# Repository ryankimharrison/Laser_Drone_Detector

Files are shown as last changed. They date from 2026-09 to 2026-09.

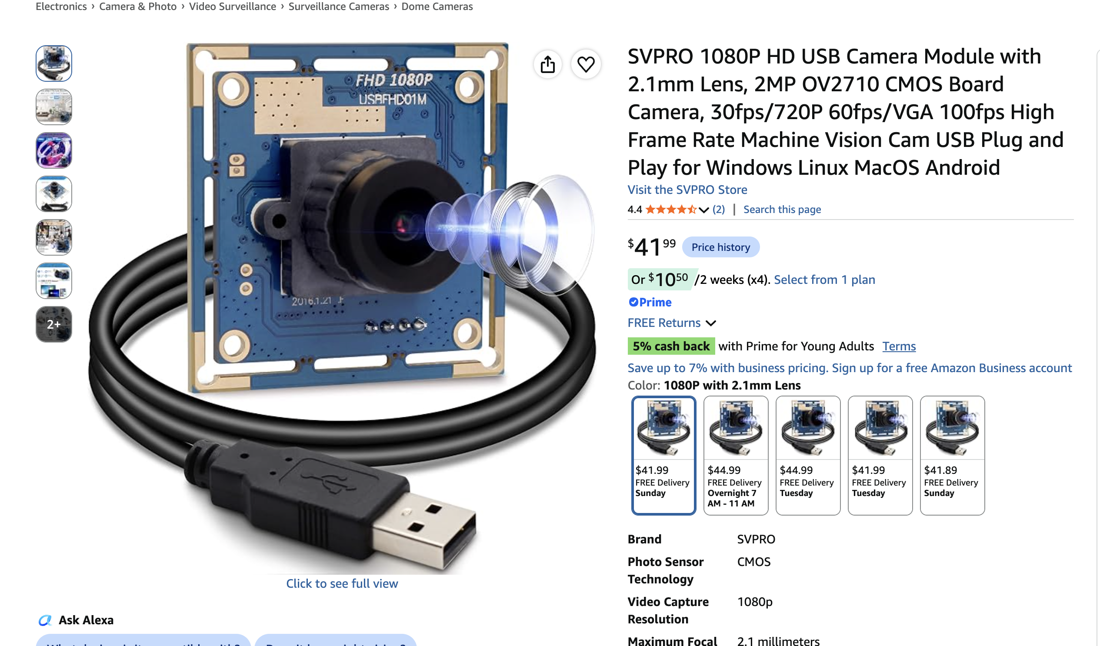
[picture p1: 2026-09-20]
unnamed (1).png

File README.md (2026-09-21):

# Laser Turret

An experimental two-camera pan/tilt tracking platform that detects a handheld DGI drone, follows it with a differential stepper mechanism, and controls a low-power green laser through a deliberately fail-closed software interlock.

This README explains both the big picture and the implementation. In plain language: a Windows computer watches two cameras, identifies the drone, estimates where it is moving, and asks a Raspberry Pi Pico to turn two motors. The laser is a separate output. Tracking the drone does **not** automatically permit the laser to turn on; a set of additional checks must all pass on every control cycle.

## What is in this repository?

| Area | Purpose |
|---|---|
| `turret_host/` | Windows/Python application: cameras, object and face detection, tracking, motion control, GUI, calibration, logging, and serial communication |
| `firmware/current/` | Current MicroPython firmware for the Raspberry Pi Pico |
| `turret-2026-03-27_134819/` | KiCad schematic and PCB layout for controller board revision `3/27/2026 prod v1` |
| `tools/` | Calibration, deployment, diagnostics, replay, registration, and analysis utilities |
| `tests/` | Host-side regression tests, principally for telemetry and microstepping |
| `dataset/`, `models/`, `weights/` | Local training data and detector artifacts; most generated content is intentionally ignored by Git |
| `firmware/backups/` | Historical, timestamped firmware snapshots; useful for archaeology, not the current implementation |
| `staged/` | Proposed patches and experiments that may not be active |

The authoritative implementation paths are `turret_host/`, `firmware/current/`, and the KiCad project. Documents such as `AGENT_HANDOFF.md`, `DETECTION_BRIEF.md`, session notes, and staged patches preserve valuable history, but some statements in them have since been superseded by measurements or code changes.

## System overview

The physical head carries a narrow camera, a wide camera, a laser, and an inertial measurement unit (IMU). Two stepper motors drive a differential wrist. The computer performs the expensive vision and tracking work; the Pico generates accurate step pulses, applies motion limits, operates switched outputs, and stops motion if host commands disappear.

```mermaid
flowchart LR
    W[Wide camera<br/>find and reacquire] --> DW[Wide detector]
    N[Narrow camera<br/>precision tracking] --> DN[Drone detector]
    N --> F[YuNet face detector]
    DW --> X[Wide-to-narrow mapping]
    DN --> T[Pixel tracker]
    X --> T
    T --> C[Controller]
    F --> I[Laser interlock]
    C --> I
    I --> L[Serial link]
    L --> P[Raspberry Pi Pico]
    P --> M[Two stepper drivers]
    P --> Q[Laser MOSFET]
    IMU[Payload IMU] --> P
    P --> L
```

The design separates responsibilities:

- The **host computer** understands images, chooses a target, predicts motion, calculates motor rates, presents status, and decides whether the laser is permitted.
- The **Pico firmware** performs deterministic pulse generation, differential kinematics, acceleration limiting, travel guarding, output control, and a 400 ms command watchdog.
- The **PCB** connects power, the Pico, plug-in stepper drivers, motor and sensor headers, and three MOSFET-switched loads.

## How one frame becomes motion

1. Dedicated capture threads continuously grab the newest narrow and wide camera frames.
2. YOLO detects candidate drones. Wide-camera detections can help find a target outside the narrow field of view.
3. A stateful pixel tracker associates detections across frames and estimates position and velocity.
4. The controller compares the predicted target position with the calibrated laser aim point.
5. A measured image Jacobian converts the required image motion into signed rates for the two motors.
6. The host sends `vel <motor-a> <motor-b>` commands over USB serial.
7. The Pico ramps toward those rates and generates step pulses using RP2040 PIO hardware.
8. If new commands stop arriving for 400 ms, the firmware ramps the motors to zero and cuts the laser.

Instead of queues, threads exchange data through a `Slot`: a one-item, newest-wins mailbox. This is important for real-time behavior. If vision falls behind, processing an old queue of frames would make the turret chase where the target *was*. A slot lets a slow consumer skip frames and act on the freshest available observation.

## Computer vision and target tracking

### Two cameras, two roles

The **wide camera** provides situational awareness and reacquisition. It is an SVPRO USBFHD01M/OV2710 module with an approximately 108° horizontal field of view. It normally runs at 1920×1080 at 30 fps, with an optional 1280×720 at 60 fps mode.

The **narrow camera** is a Logitech C270 running at 1280×720 at 30 fps. It provides the precision image coordinate system used by the tracker, controller, laser calibration, and safety checks. It is physically mounted 90° clockwise and has had its IR-cut filter removed. That improves some sensing possibilities but shifts its colors away from what ordinary pretrained vision models expect.

The wide-to-narrow transformation can steer the turret toward a target seen only by the wide camera. It includes camera rotation, focal-length scaling, and optional fitted registration. However, parallax and calibration error mean a wide-origin box is never considered precise enough to authorize the laser. The design rule is:

> **Track on either camera; fire only from current narrow-camera evidence.**

### Drone detection

`turret_host/detector.py` wraps an Ultralytics YOLO detector. The active default is the project-specific `drone_y11n_v4_1280.pt`, run at 1280-pixel input size with FP16 enabled where supported. Only the `drone` class is selected.

The detector proposes boxes; it does not by itself decide which box to follow or whether the laser may operate. Training and capture utilities support collecting in-domain images, pre-labeling them, reviewing labels, and training a small model. This matters because the real scene—a close drone held in a hand, indoors, with partial occlusion and altered camera color response—is unlike the small outdoor drones found in most public datasets.

### Association and prediction

`turret_host/tracker.py` implements a pixel-space Kalman tracker with state:

```text
[horizontal position, vertical position, horizontal velocity, vertical velocity]
```

It uses confidence, spatial gating, box geometry, and continuity to associate detections. Adaptive process noise lets it remain smooth during steady motion while responding more quickly when the target changes direction. Its state machine is:

- `SEARCH`: no reliable target.
- `ACQUIRE`: a candidate is being confirmed.
- `TRACK`: the detector and filter agree on a target.
- `COAST`: detections were briefly lost, so the filter is predicting without fresh pixel evidence.

Coasting is useful for smooth pointing but is **not** sufficient permission to fire. The interlock requires a fresh narrow-camera drone box, not just a plausible prediction.

Range is estimated from apparent drone size when possible and may be supplemented by camera geometry. The assumed physical drone width is part of the configuration, so this is an estimate rather than a depth sensor measurement.

### Motion compensation and control

The controller combines two ideas:

- **Proportional correction** moves the target toward the goal pixel.
- **Feedforward** uses estimated target velocity so the turret moves with the target instead of always lagging behind it.

The core control law is conceptually:

```text
motor rate = - inverse(image Jacobian) × (position correction + target image velocity)
```

The image Jacobian is measured during calibration by moving the mechanism and observing how a stationary scene shifts in the camera. Its sign and scale are machine-specific. Rates are clamped, derated near travel limits, and converted through the differential mechanism. Optical flow and IMU-derived platform motion can improve the velocity estimate; their quality gates and fallbacks are logged so recorded runs can be analyzed rather than tuned by impression.

## How face protection works

The active face detector is OpenCV YuNet. It runs in a dedicated thread on the **narrow camera** because CPU inference can take longer than one camera frame period. YuNet expects upright faces, so the narrow image is rotated to compensate for the camera's 90° physical mounting. Detected boxes are then mapped back to the raw narrow-camera coordinate system used by tracking and control.

The interlock measures the distance between every detected face box and the intended beam path. The path is treated as a segment between the calibrated laser goal and current target location rather than as a single point. If a face is within the configured 120-pixel exclusion margin, the laser is inhibited.

Just as importantly, a missing or old face report is treated as **unknown**, not “no face.” A stalled detector, dead camera thread, clock error, or face result older than 200 ms therefore turns the laser off.

### The laser permission checklist

`LaserInterlock` grants permission only when **all** of the following are true:

| Check | Meaning |
|---|---|
| Armed | Both configuration and the operator's deliberate arm action allow laser use |
| Tracking | The tracker is in confirmed `TRACK`, not searching, acquiring, or coasting |
| Goal calibrated | The image location where the beam lands has been physically measured |
| Fresh drone lock | A recent narrow-camera drone box exists and contains the entire beam path |
| Plausible shape | The box aspect ratio is consistent with the measured drone, rejecting a known hand-like false positive |
| Fresh face report | The face detector has reported recently enough to be trusted |
| Face clear | Every face is farther than the inhibit margin from the beam path |
| Settled | The platform angular rate is below the firing threshold |
| Aim error small | The tracked target is close enough to the calibrated beam point |
| Velocity stream fresh | A motion command was successfully sent within the last 100 ms |
| Duty limit | Continuous on-time has not exceeded the configured cap; a cooldown follows a trip |

The logic is permission-based: a current drone detection under the beam is positive evidence. Merely failing to see a face is never enough. On any failed check, the desired laser state changes to off before normal motion work continues.

Additional protections include:

- Operator stop, disarm, E-stop, shutdown, and dead-worker events set a host-side **latched safety veto**. It can only be cleared by a new human arm action.
- Arming on real hardware invokes a live face-interlock verification procedure.
- A refused firmware `laser on` is not retried forever.
- The serial writer prioritizes laser state transitions and reports when a dead link makes software unable to confirm that the beam is off.
- Firmware boot and exception paths park STEP/DIR and all MOSFET gates low.
- The velocity watchdog cuts the laser as well as stopping motion.

### What this protection cannot guarantee

The software currently detects **visible faces**, not all human heads. YuNet can miss profiles, the back of a head, heavy occlusion, poor lighting, motion blur, or a strongly tilted face. The repository records a known loss around 35° of in-plane head tilt in one test configuration. The 200 ms allowable report age also permits real-world motion within the safety margin.

Only narrow-camera faces participate in the firing veto. Wide-camera face boxes are drawn for awareness but are not geometrically calibrated into the beam coordinate system and do not gate the laser.

No software command can switch off a laser after power or serial control has failed in a state that leaves the output energized. A physical, normally-off power interlock, keyed enable, emergency stop that removes laser power, enclosure/beam stop, and appropriate protective eyewear are outside this repository and remain necessary. Cheap 532 nm DPSS modules may also emit invisible infrared unless properly filtered.

## Firmware architecture

The firmware runs on a Raspberry Pi Pico/RP2040 under MicroPython.

| Module | Responsibility |
|---|---|
| `main.py` | Safe boot, pin parking, and console startup |
| `cli.py` | USB serial command protocol and operational workflows |
| `stepper.py` | PIO step generation, position moves, velocity loop, acceleration, watchdog, and optional microstep profiles |
| `kinematics.py` | Differential transform between motor motion and payload pitch/yaw |
| `guard.py` | IMU-backed crash/travel protection |
| `imu.py` | GY-85 gyro, accelerometer, and magnetometer drivers |
| `datum.py` | Gravity/yaw datum handling |
| `endstop.py` | Endstop debouncing, homing, and repeatability tests |
| `peripherals.py` | Laser, IR light, fan, ultrasonic, analog, and I²C devices with safety checks |
| `pinmap.py` | Copper-verified board wiring; the hardware source of truth |
| `config.py` | Driver type, mechanics, limits, interlocks, and timing |
| `diagnostics.py` | Electrical and motion self-tests |

The differential wrist is not a conventional independent pan motor plus tilt motor. Both motors moving in the same direction produce pitch; moving oppositely produces yaw. Each motor by itself produces a mixture. `kinematics.py` performs this transform using the 26-tooth motor and 60-tooth miter pulley ratio.

Position moves and continuous velocity mode use RP2040 PIO state machines for deterministic pulses. A 5 ms firmware velocity tick ramps rates and enforces limits. Dynamic microstepping exists but is disabled by default because measured switching disturbances outweighed its benefit on this drivetrain.

## PCB and hardware design

The KiCad design is a single controller/carrier board centered on:

- **A1 — Raspberry Pi Pico:** USB-connected control computer and I/O controller.
- **A2/A3 — Pololu-format stepper sockets:** intended symbol is DRV8825, while the installed/configured drivers are A4988-compatible modules.
- **U1 — XL1509-5.0 buck regulator:** creates the board's 5 V rail from the external motor supply, with L1, D1, and bulk capacitors.
- **Q1/Q2/Q4 — low-side N-channel MOSFET outputs:** switch the laser, IR illuminator, and fan.
- **J2/J3:** four-wire motor coil connectors.
- **J13/J14:** endstop connectors.
- **J5/J11:** sensor/I²C connections; the GY-85 is configured on J5/I²C0.
- **J10/J9/J7:** laser, IR, and fan switched-load connectors.

The Pico is USB-powered; the PCB's 5 V rail does not feed Pico `VSYS`. Grounds are common. This means the controller does not operate as a standalone board without USB power.

### GPIO summary

| Function | GPIO |
|---|---:|
| Tilt motor DIR / STEP | 0 / 1 |
| Tilt microstep M2/M1/M0 / enable | 2 / 3 / 4 / 5 |
| Tilt driver pad 2 | 6 |
| Pan motor DIR / STEP | 7 / 8 |
| Pan microstep M2/M1/M0 / enable | 9 / 10 / 11 / 12 |
| Pan driver pad 2 | 13 |
| IR / fan / endstop 1 / laser | 14 / 15 / 16 / 17 |
| Endstop 2 | 19 |
| J5 I²C0 SDA/SCL | 20 / 21 |
| J11 I²C1 SDA/SCL | 26 / 27 |
| Analog input | 28 / ADC2 |

### Important PCB findings and rework

These are facts encoded in `firmware/current/pinmap.py` and `config.py`, not generic warnings:

1. **Tilt STEP and DIR net labels are swapped in the schematic.** The copper is usable; firmware follows the physically verified GPIO0=DIR and GPIO1=STEP mapping.
2. **Driver socket pad 2 differs between DRV8825 and A4988.** It is `FAULT` on a DRV8825 but logic `VDD` on an A4988. The current configuration drives it from a Pico GPIO as an acknowledged, marginal workaround; the documented preferred rework is a proper 3.3 V connection.
3. **RESET/SLEEP is reportedly tied to 5 V.** This violates the A4988 input limit when its logic supply is 3.3 V and is explicitly recorded as an accepted out-of-spec condition, not a safe design recommendation.
4. **Several sensor connectors expose 5 V next to direct RP2040 inputs.** The ultrasonic echo, analog sensor return, and powered endstop arrangements have no divider or clamp. RP2040 GPIO is not 5 V tolerant; only dry-contact-to-ground endstops or verified 3.3 V signals are safe.
5. **The motor connectors are mirrored.** Each keeps a coil on adjacent pins, but supplied interleaved looms must be re-pinned so each coil occupies pins 1–2 or 3–4. Incorrect wiring can make a motor buzz and overheat its driver.
6. **The TO-220 MOSFET footprint pin order did not match a standard device.** Q1/Q2/Q4 require crossed gate/drain leads or a matching pinout. Current config says this rework was completed; verify the physical board.
7. **There are no on-board I²C pull-ups.** Any attached module must provide correctly referenced 3.3 V pull-ups.

For any new revision, these should be corrected in copper instead of perpetuated as assembly workarounds.

## Homing, calibration, and coordinate systems

The turret has multiple coordinate systems: wide pixels, raw narrow pixels, upright display pixels, motor microsteps, payload pitch/yaw, and the real laser spot. Calibration is what connects them.

At startup, the normal application establishes a repeatable datum by checking the link, calibrating gyro bias, leveling from gravity, finding a yaw reference, applying a consistent backlash preload, and setting home. Pitch is observable from gravity. Yaw is not; the project uses the repeatable magnetic field of the nearby motors as a local datum rather than trusting it as a compass.

Required calibration artifacts include:

- **Image Jacobian:** how motor steps move a stationary feature in the narrow image.
- **Goal pixel:** where the real laser spot lands in the narrow image. Frame center is acceptable for aiming experiments but never for firing permission.
- **Wide-to-narrow registration:** how a wide detection maps into the narrow camera for reacquisition.
- **Camera/latency measurements:** focal geometry, exposure, frame delivery, and end-to-end delay.

Mechanical backlash was measured around 0.57°, so homing approaches the final datum from a consistent direction.

## Running the software

The recorded development environment is Windows with Python 3.12, OpenCV, NumPy, Pillow, pyserial, PyTorch with CUDA, and Ultralytics. A `.venv` directory exists in this checkout, but virtual environments are machine-specific and its Python launcher may point to an interpreter that is no longer installed. The repository currently has no reproducible lock file; treat the environment description as informative rather than a clean-install guarantee, and rebuild the environment locally when necessary.

Start safely with simulation and no GUI:

```powershell
.\.venv\Scripts\python.exe -m turret_host.app --no-hardware --no-gui --run-seconds 5
```

Run simulation with the spectator GUI:

```powershell
.\.venv\Scripts\python.exe -m turret_host.app --no-hardware
```

Run with real cameras and motion but force tracking-only behavior:

```powershell
.\.venv\Scripts\python.exe -m turret_host.app --tracking-only
```

The real-hardware default performs homing and may move the mechanism. Keep the laser power physically disconnected during commissioning. Useful options include `--port`, `--cpu`, `--wide-fast`, `--fast-home`, `--skip-level`, `--record DIR`, and `--run-seconds N`; use `--help` for the current list.

## Verification and diagnostics

Tests that do not require attached hardware:

```powershell
.\.venv\Scripts\python.exe -m compileall -q turret_host
.\.venv\Scripts\python.exe -m unittest discover -s tests
.\.venv\Scripts\python.exe -m turret_host.control
.\.venv\Scripts\python.exe -m turret_host.tracker
```

Many utilities in `tools/` intentionally talk to real hardware or cameras. Read their arguments and source before running them. In particular, deployment, homing, calibration, step, lash, and structured-light tools can cause motion or light emission.

The application can record synchronized telemetry for after-action analysis. The supporting scripts study latency, clock alignment, step integrity, image registration, optical-flow velocity, aim residuals, and mechanical skew. This measurement-first approach is central to the project: motor counts alone cannot reveal a skipped belt or stalled mechanism, and a visually smooth demo does not prove that the safety gates worked.

## Known limitations and current status

- This working tree is an active prototype with uncommitted current-code changes and staged experiments.
- Laser enable is currently `True` in both `turret_host/config.py` and `firmware/current/config.py`. The GUI still requires deliberate arming and the interlock still applies, but configuration is not a physical safety barrier.
- Face detection is a safety aid with known blind spots, not proof that no head is present.
- Wide-camera detections can steer but cannot authorize firing.
- Several camera intrinsics and offsets began as estimates; verify which calibration JSON artifacts exist on the actual machine.
- Dead reckoning can diverge when motors skip. The payload accelerometer independently measures tilt, but it cannot directly observe yaw near level.
- The software soft limits do not replace mechanical stops. The payload is documented as ±90° pitch with a ±225° yaw wiring limit.
- The host presently caps normal motor commands at 1000 microsteps/s pending further delivery testing, below firmware's higher electrical ceiling.
- Hardware notes describe accepted out-of-spec wiring. A production revision should add real level shifting/protection and a hardware laser-interlock chain.

## Design principles worth preserving

- **Fail closed:** uncertainty removes permission; it never creates it.
- **Freshness is data:** every frame, face report, detection, and command carries time information.
- **Newest wins:** discard stale work instead of building a real-time backlog.
- **Measure geometry:** do not hide sign errors or physical offsets in tuning constants.
- **Separate tracking from firing:** a prediction may steer, but only current narrow-camera evidence can permit light.
- **Independent witnesses:** use camera evidence, serial freshness, IMU attitude, firmware watchdogs, and human controls for different failure modes.
- **Preserve provenance:** a mapped wide-camera box remembers that it came from the wide camera and can never accidentally become firing evidence.

## Further reading

- `turret_host/BUILD_SPEC.md` — host design contract and hard-won implementation constraints.
- `turret_host/STATUS.md` — an older formal safety review; useful history, but some configuration values are now outdated.
- `AGENT_HANDOFF.md` — detailed hardware measurements, firmware protocol, and project history.
- `DETECTION_BRIEF.md` — rationale for the custom drone dataset and detector training approach.
- `PLAN_NEXT_STAGE.md` and session notes — experimental results and next-stage control analysis.
- `firmware/current/pinmap.py` — the copper-verified wiring source of truth.

## Responsible use

This project combines automated aiming, moving machinery, exposed electronics, and laser emission. Operate it only in a controlled indoor test area with a beam stop, exclusion zone, direct supervision, and a physical means to remove laser power. Begin with the laser disconnected and substitute a harmless indicator during software development. Compliance with local laser, electrical, workplace, and aviation rules is the operator's responsibility.

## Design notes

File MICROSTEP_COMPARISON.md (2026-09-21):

# Dynamic microstepping and fixed-mode comparison

## Faster tracking: dynamic mode

`--dynamic-microstep` now enables automatic 1/16 <-> 1/8 switching and doubles
the narrow tracking angular-speed ceiling. This is different from the fixed
A/B comparison below, which deliberately preserves angular speed.

The implementation is local and offline-tested; it has NOT been deployed or
validated on the mechanism. Deploy the updated firmware first (see below).

```powershell
./.venv/Scripts/python.exe -m turret_host.app --dynamic-microstep --tracking-only --skip-level --record diag/microstep_dynamic
```

Return to baseline with a separate launch after closing the first one:

```powershell
./.venv/Scripts/python.exe -m turret_host.app --microstep 16 --tracking-only --skip-level --record diag/microstep_baseline
```

No new camera/Jacobian/goal-pixel calibration is required solely for this
mode. The host retains fixed 1/16 units and the existing Jacobian. The new
`vel16` firmware command converts EVERY request to the current physical gear,
including commands after a shift. Calibration files are not rewritten.

With the current 1,000 pulse/s baseline:

| Behavior | Fine 1/16 | Coarse 1/8 |
|---|---:|---:|
| Physical pulse cap per motor | 1,000/s | 1,000/s |
| Nominal pure-axis angular cap | 48.75 deg/s | 97.5 deg/s |
| Angular acceleration | unchanged | unchanged |

These are commanded ceilings, not a claim that the loaded motors achieve
them. Wide-only acquisition keeps the old angular cap because its evidence
arrives more slowly. This version does not use 1/4 steps.

Shifting policy is based on the faster motor's demand in 1/16-equivalent
units: request coarse above 700/s for 100 ms; request fine below 400/s for
300 ms, and only once the ramped commanded rate is also below 400/s. There
must be at least 500 ms between shifts. Coarsening is deferred when the
existing phase estimate is unaligned; it is never forced after a timeout.
While deferred, the fine pulse cap remains in effect.

Both driver modes change with the timer ISR excluded and both PIO generators
paused. Travel limits use fixed units, counters retain fractional progress,
and `velmode off` restores 1/16 before homing/rewinding. The existing phase
estimate is dead reckoning, NOT a hardware pulse counter: software tests do
not establish physical translator alignment or absence of shift-induced
motion. First hardware runs must check for jolts, oscillation and lost steps.

For the first comparison, record baseline -> dynamic -> baseline with the
same target motions and range, starting slowly and increasing movement speed.
Use `--tracking-only` during these tests. Judge target retention and error
together with IMU motion and the shutdown return check. A higher requested
speed without delivered motion is not an improvement.

`control.jsonl` now includes `gear_ack`: the last acknowledged physical
divisor, cumulative shifts, firmware pulse-cap flag, canonical requested
rates and `ack_t`. The timestamp matters: it is a previous serial ACK, not
necessarily the command on the same control row. `session.json` records
`DYNAMIC_MICROSTEPPING`, `MICROSTEP_DIVISOR` and the actual host caps.

The host refuses dynamic firmware without protocol version 2. The firmware
refuses legacy `vel` commands while dynamic mode is enabled; use the host's
new protocol, or select `microprofile 16` while idle to leave dynamic mode.

## Fixed-speed comparison

Implemented locally; hardware validation is pending. Use `--microstep 16` or
`--microstep 8` on each application launch. Close the application completely
between runs so only one process owns the serial port.

## Firmware prerequisite

The board must have the updated `cli.py` and new `microprofile.py`. An older
board is rejected before homing; the application never silently falls back to
`ms both 8`. The normal deployment tool is:

```powershell
./.venv/Scripts/python.exe tools/deploy.py --dry-run
./.venv/Scripts/python.exe tools/deploy.py --label fixed-microstep-profiles
```

The deploy tool uploads all changed files in `firmware/current`, including any
pre-existing changes there, and resets the board. Review the dry-run list first.
No firmware was deployed as part of implementing this feature.

## A/B runs

If the old watchdog latch prevents startup, with the app CLOSED:

```powershell
./.venv/Scripts/python.exe tools/send.py "laser off" "velmode on" "velmode off" "state"
```

This clears the velocity latch; it does not test motor delivery. Confirm the
returned state has velocity stopped, both axes idle, and laser off. The
microprofile command refuses a moving or illuminated rig.

Run A:

```powershell
./.venv/Scripts/python.exe -m turret_host.app --microstep 16 --tracking-only --skip-level --record diag/microstep16
```

Run B, after A has fully closed:

```powershell
./.venv/Scripts/python.exe -m turret_host.app --microstep 8 --tracking-only --skip-level --record diag/microstep8
```

`--skip-level` retains the project's existing startup choice. It still runs
the rest of homing; it is not a way to skip setup or verify the starting pose.
Place the mechanism at the same sensible starting pose for both runs.
`--tracking-only` refuses ARM for the entire process. Press START in the GUI.
The recorder creates a timestamped run subdirectory under each requested path.

Use the same lighting, distance and target in each run:

1. Hold the drone stationary for 10 seconds.
2. Make repeatable horizontal passes, then vertical passes, then reversals.
3. Repeat increasingly fast passes, including briefly leaving the narrow view.
4. Close normally and retain the shutdown/step-integrity report.

Two runs give an initial comparison. A third 1/16 run (A/B/A), or a reversed
order repeat, helps distinguish microstepping from warming motors/drivers and
differences in hand movement. Compare visible target retention and reacquisition,
pixel error, saturation, and measured IMU motion versus commanded motion.
Exclude homing, actual travel-limit stops, and false target locks from motor
delivery comparisons. Convert pulse rates using each run's
`session.json` config `AXIS_STEP_DEG`; raw pulse rates are not comparable.

## What is preserved

The initial experiment holds angular limits constant: with the current 1,000
pulse/s baseline, 1/8 uses 500 pulse/s, yielding the same nominal 48.75 deg/s
pure-axis cap. Firmware position rates and accelerations are scaled too;
velocity acceleration is scaled exactly once. This tests whether the motor
follows more reliably/smoothly, not whether requesting twice the speed helps.
A speed-ceiling sweep is a separate hardware experiment after this passes.

The host doubles the loaded Jacobian at 1/8, halves step-based caps/preload,
and updates the angular conversion. Existing untagged Jacobian files are
interpreted as 1/16. New calibration saves record `microstep_divisor`, allowing
either mode to load them correctly. Launching alone never writes calibration.
The GUI's Jacobian calibration uses scaled probe travel. Camera intrinsics,
registration and goal-pixel files are not changed.

Switching occurs only before homing, never during tracking. Before coarsening,
the firmware may move each motor by ONE 1/16 microstep to reach a common driver
translator phase. Homing then establishes the datum. Automatic gearshifting
stays off. The selected mode remains on the board until changed or rebooted;
use `--microstep 16` to return to baseline. Launching without a profile while
the board remains at 1/8 is rejected by the existing homing geometry check.

## Offline verification

```powershell
./.venv/Scripts/python.exe -m unittest discover -s tests -p '*microstepping.py' -v
./.venv/Scripts/python.exe -m turret_host.app --no-hardware --no-gui --microstep 8 --tracking-only --run-seconds 3
```

These exercise scaling and application wiring, not physical motor delivery.

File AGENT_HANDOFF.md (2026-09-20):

# Laser Turret — agent handoff

You are building the tracking stack for a laser turret: the perception layer on
an RTX 4070 host and the velocity-mode extension to the existing Pico firmware.
This document is self-contained. Everything you need is either inline or in a
file listed in §0.3. You should not need to ask the human anything before
reaching milestone M5.

**The one requirement.** A 5 mW green laser stays smoothly on a drone held in a
person's hand, 2–5 m away, in a busy classroom, regardless of how the hand
moves. Every decision below serves that. If you find a conflict between this
document and that requirement, the requirement wins.

**Demo reality.** The drone is *held*, not flown. Someone's hand is on it,
partially covering it, and their face is 60–80 cm away. The system must fire at
the drone and never at the face. Speeds are hand speeds: ≤1 m/s, ≤3 m/s².

---

## 0. Orientation

### 0.1 What is done and verified

- Custom RP2040 PCB (rev **3/27/2026 prod v1**) designed, fabricated, brought
  up. Every pin in this document was derived from the PCB copper and is
  machine-checked (`turret_test/tests/verify_against_kicad.py`, 41 checks).
- **Seven** hardware findings diagnosed. Condensed in §1.3. Six are fixed;
  **Finding #7 (MOSFET gate/drain swapped) is NOT, and it means there is no
  working laser until the transistors are reworked** — see §1.5c.
- MicroPython bring-up firmware on the Pico with a serial CLI, a browser GUI
  bridge, **205 host-side tests**, an on-board no-motion test suite. Clean.
- Motors verified moving. Step generation measured at **0.1 % timing error
  from 200 to 20 000 steps/s**.
- Motion platform built and running; the CAD now includes the payload,
  both cameras, the IMU and the PCB.

**Added 2026-09-16 — read these, they change what you have to build:**

- **Velocity mode is BUILT** (§4.8), not a task. 200.1 Hz loop, dead reckoning
  accurate to 1 step in 1607, 43 ms host round trip, watchdog and travel limit
  enforced in the loop.
- **Backlash is MEASURED: 0.57 deg** (§6.2), well above the 0.16–0.46 deg
  estimate. At 3 m that is 30 mm of beam wander per reversal, so backlash —
  not step resolution — sets pointing accuracy on a reversing target.
- **There is a 9-axis IMU on the payload** (§1.5b): gyro for rate, accelerometer
  for an absolute pitch datum, and the magnetometer reading the motors'
  permanent-magnet field as a coarse yaw reference plus a rotor-period
  resolver signal.
- **Both cameras characterised** (§1.5, §5.2): use the **MSMF** backend, never
  DSHOW; the wide camera is 1920×1080 and is *slower* at 720p; both must be on
  separate native USB ports.
- **A 3D viewer exists** (`sim/wrist-ik.html`) that drives the real turret with
  the same closed-loop velocity scheme your tracker will use. Useful as a
  reference implementation and for testing without a drone.

### 0.2 What you are building

1. ~~**Firmware:** a velocity mode for the existing MicroPython suite.~~
   **Done — see §4.8 for the API.** You should not need to touch the firmware
   at all. If you do, `config.py` is the place; `pinmap.py` is hardware truth
   and is machine-checked against the PCB copper on every deploy.
2. **Host:** capture → detect → filter → control → serial, plus a spectator
   display (§5).
3. **Calibration tooling** for the four empirical constants the loop needs (§6).

### 0.3 Files you should have

```
turret_test/                 the working firmware + tools. READ pinmap.py FIRST.
  pinmap.py                  hardware truth. Do not edit.
  config.py                  tunables. You will edit this.
  stepper.py                 PIO step generation, Axis, coordinated_move().
  kinematics.py              the differential transform + Platform. READ THIS.
  cli.py                     serial console. You will add commands here.
  diagnostics.py, endstop.py, peripherals.py, main.py
  gui_server.py, gui.html    browser control panel (holds the COM port when running)
  release_board.py           returns the board to the REPL so mpremote can deploy
  deploy.ps1 / TURRET.bat    deploy with pin-map audit + host tests as gates
  imu.py                     GY-85 driver (gyro / accel / mag). NEW.
  tests/                     host_test.py (205), smoke_test.py, verify_against_kicad.py
  hardware/turret.kicad_pcb  the ground-truth copper
  hardware/finding7-mosfet.svg  why the laser does not work yet
  HARDWARE_NOTES.md          the SEVEN findings, in full
  BRINGUP.md                 what happened on first power-up
turret_vision/
  geom.py                    reference maths (camera model, triangulation)
  head_geometry.py           MEASURED laser/camera offsets + parallax. NEW.
  identify_cameras.py        resolve cameras by USB identity, not index. NEW.
  probe_camera.py            real delivered fps per mode per backend. NEW.
  dual_capture_test.py       both cameras at once -- USB bandwidth. NEW.
  cameras.json, camera_modes.json   what those two measured
sim/
  wrist-ik.html              3D viewer; drives the real turret closed-loop. NEW.
  serve.py                   serves it, proxies /api/*, starts the controller
  export_mesh.py             CAD -> mesh + MEASURED joint axes
TRACKING_ARCHITECTURE_v2.md  the reasoning behind §3. Read if something here seems odd.
```

If `turret_test/` is missing, stop and ask for it. Nothing else is essential.

### 0.4 Machines and ports

- **Host:** Windows, RTX 4070. Cameras and Pico all on USB.
- **Pico:** enumerates as **VID 2e8a PID 0005** when running MicroPython. Find
  it by VID/PID, never by COM number — it moved from COM3 to COM4 on the dev
  machine after a reflash and will be something else on yours.
- Only one process may hold the port. `gui_server.py` holds it while running.
  `mpremote` needs the console released first: run `python release_board.py`.

---

## 1. Hardware — facts you can rely on

### 1.1 Pin map (from copper, verified)

Two stepper drivers on Pololu-16 carriers. **The firmware calls them `pan` and
`tilt`. Those names are wrong for this platform** — they are Motor A and
Motor B of a differential (§1.4). Neither is payload pan or tilt on its own.

| firmware name | this doc | driver ref | STEP | DIR | EN | MS1/2/3 | pad 2 (VDD) | coils | RST/SLP hdr |
|---|---|---|---|---|---|---|---|---|---|
| `pan` | **Motor A** | A3 | GPIO8 | GPIO7 | GPIO12 | GPIO11/10/9 | GPIO13 | J3 | J4 |
| `tilt` | **Motor B** | A2 | GPIO1 | GPIO0 | GPIO5 | GPIO4/3/2 | GPIO6 | J2 | J1 |

EN is **active low**. Pad 2 is **VDD** on these A4988 carriers and is driven
high by the GPIO as the chip's logic supply (§1.3, finding 2).

| function | GPIO | notes |
|---|---|---|
| Laser (Q1 gate) | 17 | HIGH = on. 100 kΩ gate pulldown → off when MCU dead |
| IR LEDs (Q2) | 14 | same structure |
| Fan (Q4) | 15 | same structure |
| Endstop 1 (J14 pin 2) | 16 | switch to GND, internal pull-up, active low |
| Endstop 2 (J13 pin 2) | 19 | same |
| I2C1 SDA / SCL (J11) | 26 / 27 | **no pull-ups on the board**; IMU module supplies them |
| Ultrasonic trig / echo (J5) | 20 / 21 | echo is 5 V — locked out in config; not used |
| Analog in (J6) | 28 / ADC2 | not used |
| Free | 18, 22 | |

Pico VSYS is **unconnected**: the board cannot power the Pico. USB only.

### 1.2 Drivers

A4988 carriers, sense resistor 0.068 Ω (`SENSE_RESISTOR`), 1/16 microstepping
(MS1/2/3 = 1,1,1). Current limit set by trimpot; Vref = I × 0.544. Target
~0.7–1.0 A/phase → **0.38–0.54 V**. RST and SLP are jumpered together and tied
to **3.3 V** (not 5 V — see finding 4).

### 1.3 The six findings, condensed

You will not hit these; they are fixed. You need them to avoid undoing them.

| # | what | state |
|---|---|---|
| 1 | Schematic's tilt STEP/DIR *labels* are swapped. Copper is right; `pinmap.py` follows copper. | handled; audit enforces it |
| 2 | Driver pad 2 is FAULT on DRV8825 but **VDD** on A4988. Firmware drives it HIGH as logic supply (`A4988_VDD_SOURCE="gpio"`). | handled |
| 3 | J5/J6/J13/J14 carry 5 V; RP2040 is not 5 V-tolerant. Only bare switches on endstops. | locked out in config |
| 4 | RST/SLP must be 3.3 V for A4988 (abs max is VDD+0.3). Was 5 V; reworked. | done |
| 5 | J2 and J3 have **mirrored** pin orders; the motor loom was interleaved. Loom re-pinned (BLK BLU GRN RED). | done |
| 6 | No local VMOT decoupling, no ground pour. Chopper hiss. Bodge caps recommended. | cosmetic |

Two consequences for you: **the two axes will turn opposite ways for the same
command sign** (finding 5 — handle with the sign constants in §4, not by
re-crimping), and **never plug or unplug a motor with VMOT live**.

### 1.4 Motion platform — the differential

A bevel-gear differential wrist. Two steppers off the moving assembly drive
input bevels through 26T->60T belts (**2.3077:1**), miters 1:1. Cameras and laser sit
on the output gear.

- Both motors turning the **same** way → carrier rotates → **pitch** (up/down)
- Both motors turning **opposite** ways → output gear spins → **yaw** (left/right)
- Any single motor moving alone → equal parts pitch and yaw

**Pitch is the outer joint.** The carrier pitches about the fixed axis; the
output gear yaws about an axis *carried by* the carrier, which is tilted 11°
off nominal in the CAD's rest pose. So the yaw axis moves with pitch.

**`kinematics.py` already implements all of it** — `Platform.move_by(pitch,
yaw)` drives both motors together, and `stepper.coordinated_move()` puts them
on one shared timeline so they start and finish on the same tick. Use it for
homing, calibration and any manual positioning.

**The tracking loop still does not need it.** The control loop uses an
empirically calibrated 2×2 matrix (§6.3) that maps pixel error directly to motor step
rates, and that matrix contains the belt ratio, the differential, the joint
order and the axis tilt. The analytic form is in Appendix A for understanding
and for the pitch deck.

| quantity | value |
|---|---|
| resolution, both motors stepping | **0.04875° per axis-step** at 1/16 |
| resolution, one motor stepping | 0.024375° in *each* axis (diagonal) |
| beam travel per axis-step at 3 m | 2.55 mm |
| max payload rate at 4000 steps/s | ~195 °/s (indoor need: <40 °/s) |
| payload accel at `ACCEL=20000` | ~975 °/s² |
| gear backlash, estimated | 0.16–0.46° (SLS PA12 tooth clearance); belts negligible |

### 1.5 Optics and sensors

| item | part | key facts |
|---|---|---|
| narrow camera | Logitech C270, **IR-cut filter removed**, **mounted rotated 90°** | 1280×720 **30 fps** (MSMF), rolling shutter, f ≈ 1400 px. 49° across the sensor's long axis → **28.8° horizontal as mounted**. Refocus after the filter removal. |
| wide camera | generic UVC module, 120° M12 — **`32E4:9230`, "HD USB Camera"** | **1920×1080 max** (measured), rolling shutter, ~105° horizontal, **f ≈ 730 px**, heavy barrel distortion |
| laser | **532 nm green, 5 mW**, Class 3R | on the payload between the cameras |
| IMU | GY-85 (ITG3205 + ADXL345 + HMC5883L) | I2C on J11: 0x68 / 0x53 / 0x1E |
| target | black quadcopter, ~283 mm diagonal, ~90 mm body, held by hand | |

At 3 m the C270 puts **~132 px on the drone, ~37 px on the battery.** That is
enough. Keep native resolution — do not downscale the narrow camera, ever.

#### The wide camera is not the 5 MP module this document used to claim

Measured, with the module physically connected and the frame visually
confirmed (index 1, `32E4:9230`):

- **1920×1080 is the ceiling.** Requests for 2592×1944, 2048×1536 and 4K all
  clamp to 1080p on *both* DSHOW and MSMF. Earlier revisions of this document
  specified a 2592×1944 IMX335; that was wrong.
- **It reports no serial** — only a location id (`6&112b2957&0&3`) that changes
  when you move the USB plug. See §1.5a below; this breaks the resolve-by-serial
  plan for this camera specifically.
- Generic descriptor ("HD USB Camera", empty vendor string), no microphone.
- **1920×1080 @ 30.3 fps on MSMF, and 720p is a trap** — it delivers 9 fps.
  Full table in §5.2. Run it at native resolution.

Consequences, both of which matter:

**Pixel budget.** ~105° across 1920 px is **~18 px/deg**, not the ~29 px/deg a
2592-wide sensor would give. Angular resolution on the wide camera is down
~38 % from the old assumption. It is still only a finder — it hands off to the
narrow camera — so this is survivable, but the hand-off happens later and the
minimum detectable target is correspondingly bigger. Re-check the acquisition
range budget against 18 px/deg before trusting it.

**Barrel distortion is severe and must be corrected.** The 120° M12 lens bows
straight lines visibly across the whole frame. A pixel error near the edge does
**not** correspond to the same angle as the same pixel error at centre, so the
2×2 image Jacobian is *not* constant across the field — which is exactly the
assumption §6 currently makes. Either:

1. undistort (`cv2.initUndistortRectifyMap` once, then `remap` per frame — a
   few hundred µs on GPU) and servo on undistorted pixels, or
2. calibrate the Jacobian at a 3×3 grid of field positions and bilinearly
   interpolate.

Option 1 is less work and less to get wrong. Either way, **run a chessboard
calibration on the wide camera** (`cv2.calibrateCamera`, ~20 views) to get real
intrinsics; the f ≈ 730 px above is derived from the FOV spec, not measured,
and on a fisheye-ish M12 lens that estimate is soft. Consider `cv2.fisheye` if
the standard model's reprojection error exceeds ~1 px.

The narrow C270 is mildly distorted by comparison, but calibrate it too — it is
the camera the laser actually aims through.

#### Offsets — MEASURED, no longer TBD

Read out of `sterolaserview.step` with a CAD kernel and confirmed by the
builder. All three features lie on one line, `y = 0`:

```
     wide (120°)            laser             narrow (60°, C270)
     x = -30.000 mm      x = 0.000 mm            x = +30.000 mm
```

| constant | value |
|---|---|
| `LASER_TO_NARROW_MM` | **+30.000** |
| `LASER_TO_WIDE_MM` | **−30.000** |
| `STEREO_BASELINE_MM` | **60.000** |
| vertical offset, any pair | **0.000** |

They are in `turret_vision/head_geometry.py` with the parallax maths; import
them, do not retype them. Identification was confirmed by bore radius and boss
height — narrow 8.500 / 1.700 mm, wide 8.000 / 1.400 mm; the narrow mount is
the taller boss.

**No vertical offset is a real simplification — with one catch.** Parallax
between a camera and the beam is purely horizontal *in the payload frame*. The
image sensors sit at the same height (builder confirmed), so this holds
physically. But **the C270 is mounted rotated 90°**, so in *its* frame that
horizontal offset lands on the sensor's vertical axis: its parallax correction
goes on the goal **row**, the wide camera's on the goal **column**. Apply the
simplification per camera, not globally.

**The lenses sit at different depths** — the M12 barrel protrudes far more than
the C270's. The sensors are level with each other, so this is an axial offset
only. For parallax it is negligible (a 20 mm axial offset changes the
correction by <0.1 px at 3 m). For stereo it is not: the pair is not
fronto-parallel, so rectification will rotate and crop. Let `stereoCalibrate`
solve it; never hand-write a rectification assuming coplanar centres.

#### The C270 is mounted rotated 90° — confirmed

| | horizontal FOV | px per horizontal degree |
|---|---|---|
| as specced | 49.0° | 26.1 |
| **as mounted** | **28.8°** | 25.0 |

Angular resolution is unchanged — same lens — but the **horizontal field shrinks
by 41 %**, and the vertical grows to 49°, which is the wrong axis for a target
that mostly moves side to side. The tracking window is narrower than every
earlier estimate in this document assumed; combined with the wide camera's
18 px/deg, **the acquisition envelope is now the thinnest part of the design.**
Re-check it before tuning anything else.

The sign (90° vs 270°) is **not yet verified** and cannot be read from a single
frame. Getting it backwards inverts the parallax correction rather than merely
misplacing it — the dot lands on the wrong side and doubles the error. Confirm
against a known target before trusting it.

**Do not rotate every frame to "fix" this.** That is a full-frame copy per
frame for no benefit. Carry the rotation in the geometry, where pixel error is
converted to a correction, and rotate only the spectator display.
`turret_vision/head_geometry.py` holds `NARROW_ROTATION_DEG`.

**Parallax is not optional.** At 3 m the beam lands 14 px from where the narrow
camera says the target centre is — 0.573°, or **11.8 turret steps**. At 2 m it
is 21 px. Uncorrected, the dot sits beside the drone at close range and the
error *shrinks* as the target retreats, which reads exactly like a mis-tuned
gain and is not one.

#### The cameras are not guaranteed parallel — and stereo is brutally sensitive to it

They sit in a 3D-printed shell. With only a 60 mm baseline the true disparity
is small (28 px at 3 m), so a small relative rotation swamps it:

| relative yaw | stereo range reported at a true 3 m |
|---|---|
| 0.10° | 2.76 m (−8 %) |
| 0.25° | 2.46 m (−18 %) |
| 0.50° | 2.09 m (−30 %) |
| 1.00° | 1.60 m (**−47 %**) |

One degree of print skew nearly halves the reported range. Stereo range good to
10 % at 3 m needs the relative rotation known to **~0.1°**, which no printed
part gives you by construction.

That is what `cv2.stereoCalibrate` is *for* — it measures the rotation instead
of assuming it — so this is a calibration requirement, not a design flaw. But:

1. **Stereo range is unusable until a stereo calibration has been run.** Do not
   ship a hard-coded rectification.
2. The calibration holds only while the shell does. Anything that flexes or
   reseats a camera invalidates it **silently** — the range just goes wrong.
3. **Cross-check stereo against apparent-size range every frame.** A
   persistent, range-dependent disagreement means the extrinsics moved. This is
   the only warning you will get, and it is nearly free.
4. Seed the calibration with the known 60.000 mm baseline and treat a solved
   baseline far from it as a *failed calibration*, not a discovery.

**Do not let this block the tracking loop.** Assuming a flat 3 m across the
whole 2–5 m envelope costs at most **7 px** of aim error, against a drone that
is 132 px wide at 3 m:

| true range | 2.0 m | 2.5 m | 3.0 m | 4.0 m | 5.0 m |
|---|---|---|---|---|---|
| residual | −7.0 px | −2.8 px | 0 | +3.5 px | +5.6 px |

So aiming at the drone *body* works with **no range estimate at all**. Build
the loop against `ASSUMED_RANGE_M = 3.0`, get it tracking, then add ranging to
tighten it. Ranging earns its keep for aiming at something small like the
battery (37 px at 3 m), not for hitting the airframe.

**Prefer apparent-size range over stereo when the box is clean.** A 2 px error
on a 132 px box is ~1.5 %; a 1 px stereo match error is ~3.6 %, and matching
across a 49° and a 105° camera makes 1 px optimistic. The catch is the demo:
a hand partially covers the drone, and occlusion shrinks the apparent size and
biases size-range **long**. Stereo does not fail that way. Use size when the box
looks clean, stereo when it does not, and treat a standing disagreement as
evidence the box is clipped.

#### 1.5a Resolving camera indices — the two cameras need different methods

OpenCV indices are not stable. `turret_vision/identify_cameras.py` records the
USB identity of each camera; resolve against it at startup. But the two cameras
do not offer the same handle:

| camera | VID:PID | serial | resolve by |
|---|---|---|---|
| narrow (C270) | `046D:0825` | `C8258920` (real) | **serial** — fully stable |
| wide | `32E4:9230` | none | **VID:PID + max-resolution fingerprint (1920×1080)** |

The wide camera has no stable identity of its own. Do not buy a second
identical module, and if a camera is ever swapped, re-run `identify_cameras.py`
and update the record.

**Read the Status column in that tool's output.** Windows keeps a registry
entry for every camera ever plugged into the machine, and a stale entry looks
identical to a live one except for Status. During bring-up this caused a wrong
identification: a disconnected module (`32E6:9221`, Shenzhen Icspring — which
*does* have a mic and a real serial) was read as the connected wide camera.
That is a different device and is not part of this build.

**The cameras may be replaced.** If a global-shutter ≥90 fps USB 3 camera
(AR0234 class) lands in the narrow slot, every "30 fps" note in this document
relaxes and nothing else changes. Design for 30 fps; do not hard-code it.

**The IMU:** good for finding level (non-contact homing, ~0.5°), detecting a
bump, and measuring backlash. **Useless for yaw** — the magnetometer cannot
work next to stepper motors. Not accurate enough to replace step counting.
Optional for M1–M6.

### 1.5b The payload IMU — GY-85, new 2026-09-16

There is now a 9-axis IMU **on the payload**, and it is the first thing in this
project that measures what the mechanism actually did rather than what the
firmware believed it commanded.

**Wiring — the ultrasonic connector, J5, used as a second I2C bus.**

| J5 pin | net | GPIO | GY-85 |
|---|---|---|---|
| 1 | GND | — | GND |
| 2 | `/Ultrasonic Echo` | GPIO21 | **SCL** |
| 3 | `/Ultrasonic Trig` | GPIO20 | **SDA** |
| 4 | `/5V` | — | VCC_IN |

Verified against RP2040 datasheet Table 2: GPIO20 F3 = I2C0 SDA, GPIO21 F3 =
I2C0 SCL. This is **I2C0**, a different peripheral instance from J11's I2C1 on
GPIO26/27, so both can run at once.

Note the order reads backwards from intuition -- "Echo" is the clock and
"Trig" is the data. And beware that this board has two different "26/27":
GPIO26/27 is J11's bus, while the Pico *physical pads* 26/27 are GPIO20/21,
which is this bus.

Addresses confirmed live on the bus: **0x68** ITG3205 gyro, **0x53** ADXL345
accelerometer, **0x1E** HMC5883L magnetometer. `IMU_PORT = "J5"` in config.

**What each sensor is worth here.**

*Gyro — the useful one.* Angular rate directly, at up to 1 kHz, measuring the
payload rather than the step counter. If you want an inner rate loop under
your pixel loop, this is what feeds it. **Calibrate it:** the X-axis bias
measured **85.8 LSB = 5.97 deg/s**, repeatable across runs. Uncorrected that
fabricates a full revolution of apparent rotation per minute and looks exactly
like mechanical drift. `imu cal` averages 400 samples with the payload still;
MEMS bias moves with temperature, so re-run it when the board is warm.

*Accelerometer — an absolute PITCH datum, static only.* Gravity does not move,
so this gives a repeatable home that survives power cycles, unlike "wherever
someone typed dzero". The `level` command uses it (see §4.8 command list).
**It is static-only for a concrete reason:** the IMU sits 49.6 mm from the
wrist centre, so angular acceleration appears as tangential acceleration --
0.17 g at `VEL_ACCEL = 40000`, about 10 deg of apparent tilt. Only trust it
when the payload is stopped and settled.

*Magnetometer — no earth-field yaw, but something better.* It is inches from
two steppers and their field swamps the earth's, so a compass heading is not
available. However the **motors' permanent-magnet field is fixed in the base
frame and rotates in the IMU frame as the payload yaws**, and that is
measurable:

- coarse trend **-4.96 LSB/deg** on `my`, monotonic over the 10 deg swept
- fine ripple **4.0 LSB at a 3.07 deg period**, against 3.12 deg predicted
  from the rotor (7.2 deg of motor shaft / 2.3077 belt ratio) -- a 1.7 % match
- static field 1265 LSB (~92 uT), not saturated, noise ~1 LSB after averaging

So there is a coarse absolute yaw reference **and** a resolver-like fine signal
whose period is set by the rotor, i.e. **independent evidence of where the
mechanism really is**. Comparing its phase against commanded position is a
direct lost-step detector. Not usable as tracking feedback -- the HMC5883L
caps at 75 Hz -- but valuable as a health check and a datum.

(Switching the coils as an active beacon was tried and does **not** work: the
field change at 114 mm is 1.1 LSB against 3-5 LSB of noise. The passive rotor
field is the signal, not the coils.)

**Kinematics confirmed as a side effect.** `level` measures real tilt per
commanded degree and got **1.072**, expected 1.0 -- independently confirming
`DIFFERENTIAL_N`, the 26T pulley, the microstep setting and the sign together.

### 1.5c The laser — wiring, and why it does not work yet

| | |
|---|---|
| control | **GPIO17** -> R1 100 ohm -> Q1 gate; R4 100k gate pulldown |
| load | J10, between the connector's 5 V pin and Q1's drain |
| logic | GPIO HIGH = laser ON |

**It is currently blocked in firmware, on purpose.** `MOSFET_PINOUT_FIXED =
False` in config makes `laser`, `ir` and `fan` refuse. See
`HARDWARE_NOTES.md` **Finding #7**: Q1/Q2/Q4 are laid out **D,G,S** but a
standard TO-220AB N-MOSFET is **G,D,S**, so pads 1 and 2 are swapped. Fitted
as-is the gate is pulled to +5 V through the load (FET permanently on, laser
never lights) and driving the GPIO sinks ~33 mA against a 12 mA maximum. The
documented interlock -- "100k gate pulldown, so it is off whenever the MCU is
unpowered" -- **does not hold either**, because R4 ends up on the drain.

Fix is to cross pins 1 and 2 on the through-hole part, then set the flag True.
Until then assume you have no laser.

**Pulse mode, for dot detection.** `laser pwm [hz] [duty]` runs a hardware PWM
pulse train; default **15 Hz**, which is deliberately *half* the 30 fps capture
rate so the dot is present in one frame and absent in the next. Difference
consecutive frames and the static scene cancels, leaving only the modulated
dot. That matters because the narrow camera has had its IR-cut filter removed,
which substantially weakens the `G - max(R,B)` chroma test in §5.6. Hardware
PWM, not a timer loop, so it does not jitter against the 200 Hz velocity ISR.
If you change the capture frame rate, change `LASER_PULSE_HZ` with it.

### 1.6 Safety rules — not negotiable

1. **The only real e-stop is cutting motor power (VIN).** The software e-stop
   works only while firmware is alive. Put a physical switch on VIN.
2. Laser on **only** when: a track is confirmed, no face within the inhibit
   margin, the platform is settled, and a `vel` was received in the last
   100 ms. Any one failing → laser off, before anything else happens.
3. `LASER_MAX_ON_MS` hard cap stays. `LASER_ENABLED=False` stays until the
   beam path is safe and the face interlock is tested.
4. Never plug/unplug a motor with VMOT applied.
5. Do not run motion tests with anyone in front of the platform until M5 passes.

---

## 2. What exists: the MicroPython suite

### 2.1 Connect

```
python -m mpremote connect list          # find the 2e8a:0005 port
python release_board.py                  # if the console is running
python -m mpremote connect COMx repl     # interactive
```

`main.py` runs a console at boot with prompt `turret> `. Ctrl-C is the panic
stop (parks everything, stays in the console). Two Ctrl-C within 1 s exit to
the REPL. `quit` also exits.

### 2.2 Commands you will use

```
state                       one line: STATE {json}

  -- differential (payload axes) --
diff                        resolution, position, ratio, signs
pitch <deg> [dps]           pure pitch: both motors together
yaw <deg> [dps]             pure yaw: both motors opposed
dmove <dpitch> <dyaw> [dps] relative payload move, both at once
aim <pitch> <yaw> [dps]     absolute payload move
dzero                       set this pose as payload zero
dchar [steps]               characterise the differential (MANUAL)
dsign pitch|yaw|A|B         flip a sign for this session

  -- motors (neither is a payload axis) --
enable|disable <pan|tilt|both>
move <axis> <steps> [rate]  counted trapezoidal move, blocking
deg <axis> <deg> [rate]
ms <axis> <1|2|4|8|16>
zero <axis>
home <axis>                 3-phase homing on the assigned endstop
laser on|off|pulse <ms>     refused unless LASER_ENABLED
stop                        disable all, outputs off
safe                        the no-motion test suite
wiring                      coil connector reference
```

`state` JSON:

```json
{"payload":{"pitch":0.0,"yaw":0.0,"axis_step_deg":0.04875,"N":2.3077},
 "axes":{"pan":{"enabled":false,"microstep":8,"position":0,"degrees":0.0,
  "steps_per_rev":1600,"fault":null,"pad2":"vdd-from-gpio","has_endstop":true},
  "tilt":{...}},
 "endstops":{"pan":{"gpio":16,"triggered":false,"raw":1},"tilt":{...}},
 "outputs":{"laser":false,"ir":false,"fan":false},
 "driver":"A4988","laser_enabled":false,"rst_slp":"3V3",
 "max_rate":{"pan":4000,"tilt":4000}}
```

`position` is in microsteps of the *current* `microstep` setting.

### 2.3 Deploy

```
powershell -ExecutionPolicy Bypass -File deploy.ps1          # gates + copy
python tests/verify_against_kicad.py                        # must pass
python tests/host_test.py                                   # must pass
```

`deploy.ps1` refuses if the pin map disagrees with the copper. Keep it that way.

### 2.4 How step generation works today (you will add a second mode)

Each axis owns one PIO state machine (`pan`→sm 0, `tilt`→sm 4) running:

```
out(x, 32)          ; one FIFO word per step = extra delay cycles
set(pins,1) [7]     ; 8-cycle high pulse
set(pins,0)
hold: jmp(x_dec, hold)
```

at 1 MHz, overhead 11 cycles. `Axis.move()` streams a trapezoidal profile of
delay words into the FIFO. Two register-level helpers exist and you will reuse
them: `_set_funcsel(gpio, PIO0|PIO1|SIO)` hands the STEP pad between PIO and
SIO (MicroPython does not do this for you), and `_clear_fifos(sm_id)`.

`Axis._claim_step_pin()` / `_release_step_pin()` wrap those. **Call
`_claim_step_pin()` before activating any SM on that pin**, or the pad stays
under SIO and no pulses come out — this bit us once already.

---

## 3. The tracking design

Close the loop on the **pixel**, not on angles. The cameras ride on the payload
with the laser, so a detection in the narrow camera *is* the pointing error.
The laser dot should sit at a known pixel `g` (depends weakly on range); the
target is at pixel `p`; drive `p` onto `g`.

```
C270 frame (native res)
   │
   ▼
detector → bbox → aim-point stabiliser (§5.5)
   │
   ▼
pixel Kalman  x = [u, v, u̇, v̇]   adaptive Q   → predict to (t_now + L)
   │
   ▼
goal g = g(R)                                   §6.4 — or the detected dot, §5.6
   │
   ▼
e = p̂ − g            (px)
ω = J⁻¹ · (K·e + p̂̇)  (motor steps/s, per motor)     ← feedforward + proportional
   │
   ▼
serial:  vel <ωA> <ωB>          every frame
   │
   ▼
Pico: accel-limit, hold rate in PIO, watchdog, dead-reckon position
```

**Why feedforward is the whole game.** With ~50–70 ms of loop latency the
proportional term is only stable up to ~2 Hz. It cannot chase a hand. The
`p̂̇` term commands the turret at the *target's* angular rate continuously, so
between frames the laser is already moving with the drone; `K·e` only trims.

**Why this survives sloppy calibration.** In an angle-based chain every
calibration error is a miss on the target. Here they all live inside `J` and
`g`, and the loop tolerates `J` being 20 % wrong — it becomes a gain error the
P-term absorbs.

**What is empirical, and only these four:** `L` (latency), lash (steps), `J`
(2×2), `g(R)` (two constants per axis). §6 has the procedures.

---

## 4. Firmware: velocity mode — **BUILT, DEPLOYED AND MEASURED**

> **Do not build this. It exists.** Everything in §4.1–4.7 below describes how
> it was built and why, and is kept because the reasoning still matters — but
> the work is done, on the board, and verified on hardware. **§4.8 is the API
> you actually call.** Read that first.
>
> Measured on hardware, 2026-09-16:
>
> | check | result |
> |---|---|
> | control loop rate | **200.1 Hz** (target 200) |
> | dead reckoning, 8 s at 200 steps/s | **1608 steps** vs 1607 predicted |
> | host command round trip | **43 ms** median, 55 ms worst |
> | watchdog | trips correctly; `vel 0 0` stops cleanly |
> | host-side tests | 205 passing |
>
> Two traps were found the hard way and are fixed; both are described in §4.8
> because they will bite anyone extending this.

Extend `stepper.py` and `cli.py`. Do not touch `pinmap.py`. Keep every
existing command working — `move`, `home`, `safe` and the tests are your
regression suite.

### 4.1 The PIO program

A **second** state machine per axis (`pan`→sm 1, `tilt`→sm 5), same `set_base`
pin, running a period-register program at **5 MHz**:

```python
@rp2.asm_pio(set_init=rp2.PIO.OUT_LOW)
def _vel_program():
    label("top")
    pull(noblock)          # FIFO empty -> OSR <- X  (keeps last period)
    mov(x, osr)            # X = period, persists across iterations
    jmp(not_x, "top")      # period 0 = idle, no pulses, keep polling
    mov(y, x)              # Y = loop counter (X must survive)
    set(pins, 1) [7]       # 8 cycles = 1.6 us high  (A4988 min 1 us)
    set(pins, 0)
    label("hold")
    jmp(y_dec, "hold")     # Y+1 cycles
    jmp("top")
```

Cycles per step = **15 + Y**. So for a rate `r` steps/s:

```
period = round(5_000_000 / r)
Y      = max(0, period - 15)
```

Rate quantisation at 5 MHz is ≤0.006 % at 300 steps/s — no fractional
accumulator needed.

`pull(noblock)` on an empty FIFO copies X into OSR (RP2040 datasheet §3.4.7).
That is what makes the period persist without the CPU feeding anything.

### 4.2 Updating the period without FIFO build-up

Do **not** just `sm.put()` every tick — at low step rates the 4-deep FIFO fills
with stale periods and the rate lags by four steps. Instead:

```python
def _set_period(self, y):
    sm = self.vel_sm
    sm.put(y)
    sm.exec("pull(noblock)")   # our word is there -> into OSR
    sm.exec("mov(x, osr)")     # X = new period, immediately
```

X is only read at the top of each step (`mov(y,x)`), so clobbering it
mid-hold-loop is harmless. Takes effect within one step at any rate. FIFO ends
empty every time.

### 4.3 The velocity loop (200 Hz `machine.Timer`)

Per motor, state: `target_rate`, `current_rate`, `dir`, `pos_f` (float, dead
reckoned), `t_last_vel_ms`.

```
every 5 ms:
  if now - t_last_vel_ms > 100:            # watchdog
      target_rate = 0; laser off (direct GPIO write, not via CLI)
  dr = target_rate - current_rate
  step = min(|dr|, ACCEL * 0.005)          # accel limit, steps/s per tick
  current_rate += sign(dr) * step
  if sign(current_rate) != dir and current_rate != 0:
      _set_period(0)                       # stop
      sleep_us(300)
      set DIR pin
      dir = sign(current_rate)
  _set_period(y_for(|current_rate|))       # 0 if current_rate == 0
  pos_f += current_rate * 0.005
```

Keep the timer callback allocation-free: pre-compute everything, use ints where
you can, no string formatting inside it. MicroPython timer callbacks cannot
allocate.

`ACCEL` here is per-motor microsteps/s². The existing `config.ACCEL = 20000`
is a sane start.

### 4.4 Mode switching

`Axis` gains `mode ∈ {"idle","move","vel"}`. `move()` and `single_step()`
refuse when `mode=="vel"`; `vel` command refuses when a `move` is in progress.
Switching into vel: `_claim_step_pin()`, `move_sm.active(0)`, `vel_sm.active(1)`,
`_set_period(0)`. Switching out: `_set_period(0)`, wait 2 ms, `vel_sm.active(0)`,
`_release_step_pin()`, fold `pos_f` into `position`.

### 4.5 New commands

```
vel <A_steps_per_s> <B_steps_per_s>   signed. Enters vel mode on both if needed.
                                       Resets the watchdog. Replies "ok".
vel 0 0                                stop (still in vel mode, rate 0)
velmode off                            leave vel mode, back to move mode
preload <steps>                        move A +steps, B -steps (counted), then zero
                                       both. Takes up gear lash. See §6.2.
lash?                                  prints the stored lash constants
signs <±1> <±1>                        stored sign flip per motor (config)
```

**Motor A ≡ `pan` ≡ A3. Motor B ≡ `tilt` ≡ A2.** The `vel` arguments are
per-motor step rates after the sign constants — the host's `J` already
accounts for the differential, so the Pico never needs to know pitch from yaw.

Extend `state` with `"mode"`, per-motor `"rate"`, and `"vel_age_ms"`.

### 4.6 Position while in vel mode

Dead-reckoned from commanded rate × time. Exact to within one step per rate
change because the PIO runs the commanded period exactly. Good enough: the
closed loop corrects any residual every frame, and absolute position only
matters for homing, which uses `move`.

*(Optional, later: count real steps by DMA from the PIO's RX FIFO with a `push`
added after each pulse. Not needed for the demo.)*

### 4.7 Tests to add

To `tests/host_test.py`, against the existing `fake_hw` stubs: period math,
accel limiting, direction-change sequencing, watchdog trip, and that `move`
refuses in vel mode. Extend `fake_hw.StateMachine` with `exec()`.

On hardware: `vel 200 200` for 10 s, then `state` — dead-reckoned position
should read ~2000 ± 10 on each motor. `vel 0 0` — motors silent within
`2000/20000 = 100 ms`. Let the watchdog trip — verify rate decays and the
laser GPIO reads low.

---

### 4.8 The API you actually call

Everything below is on the board now. Commands go over the serial console
(115200, USB CDC), one line each.

```
vel <A_steps_per_s> <B_steps_per_s>    signed MOTOR rates. Enters velocity
                                       mode on both axes if needed. Resets the
                                       watchdog. Replies "ok".
pvel <pitch_dps> <yaw_dps>             signed PAYLOAD rates, deg/s.
                                       Replies "ok <pitch> <yaw>" -- the
                                       current pose, so one round trip carries
                                       both the command and the measurement.
velmode off                            leave velocity mode, back to move mode
velmode status                         rate, mode, tick count, watchdog trips
vel 0 0                                stop, stay in velocity mode
```

**Use `vel`, not `pvel`, for the tracking loop.** Your image Jacobian already
maps pixel error straight to motor rates, so going through payload angles just
adds a conversion that can carry a sign error. `pvel` exists for driving by
hand and for the 3D viewer.

**`pvel` returns the pose in its reply, and you should use that rather than
polling `state`.** Two requests contend for one serial link: each blocks the
other, feedback latency roughly doubles, and the watchdog then parks the
motors in the gap. That produced a turret that stepped between poses instead
of tracking, and it took a while to diagnose. One request, one answer.

**The watchdog is 400 ms** (`VEL_WATCHDOG_MS`). No `vel` within that window
and both rates ramp to zero and the laser is cut by direct GPIO write. It must
stay longer than your command period — it was 150 ms against a 190 ms round
trip at one point, which parked the motors between *every* update.

**The pitch travel limit is enforced every tick**, in the loop, not just in
the move path. `vel`/`pvel` are rate commands and never touch the move-path
limit check, so without this the firmware would drive the payload through the
yoke at a steady rate. Because pitch is the *sum* of the two motor positions
on a differential, the check is one integer comparison; when it bites, the
pitch component is stripped from the command and the yaw component kept, so
the payload stops tilting, can still turn, and can always drive back off the
stop.

#### Two traps, both found on hardware

**1. Read `vel_position`, never `position`, while in velocity mode.** The
integer step counter is frozen there — distance covered lives in a
dead-reckoning accumulator until the mode is left. `Platform.position()` does
this correctly now. It did not at first, and the result was a runaway: the
host servoed on a value that never changed, so the error never shrank, so it
commanded rate forever. The firmware watchdog cannot save you from this,
because the host is petting it faithfully the whole time. **If you write your
own feedback path, add a staleness check:** commanding real rate for more than
a second with no measured movement means the feedback is lying, not that the
gains need tuning.

**2. The 200 Hz tick runs in an interrupt and must not allocate.** MicroPython
cannot run the heap allocator inside an ISR. The first version used floats and
iterated a dict — both allocate — and exhausted the heap, at which point USB
CDC stopped being serviced and the board needed a power cycle. It is now
integer-only with the two axes bound to plain attributes and the PIO
instructions pre-encoded via `rp2.asm_pio_encode`. **The test suite could not
catch this**, because the fake timer calls the callback in normal context
where allocation is legal; there are now tests asserting the *properties* that
made it allocate instead.

#### Dynamic microstepping exists but is OFF

`VEL_GEARSHIFT` (default `False`) shifts microstepping with commanded speed.
It is correct and tested — including the A4988 datasheet's requirement to
change step mode only at a position common to both modes, judged against a
translator-phase counter that `zero`/`dzero` cannot move. It is off because it
caused oscillation and buys nothing here: in velocity mode the PIO free-runs,
so 1/16 already reaches ~585 deg/s of payload against a platform that tops out
near 195. Turn it on only if a measurement shows step rate is limiting
something.

---

## 5. Host software

Python 3.11+, Windows, RTX 4070. Packages: `opencv-python`, `numpy`, `torch`
(CUDA), `ultralytics`, `pyserial`. TensorRT export via ultralytics.

### 5.1 Process and thread layout

```
process: tracker
  thread capture-narrow   MSMF, grab loop, newest-wins slot, timestamps
  thread capture-wide     same
  thread inference        owns CUDA; detector on narrow (every frame) + wide (search)
  thread control          Kalman, gating, control law, serial vel
  main thread             spectator display at ≤30 fps from a 640×360 copy
```

**Slots, not queues.** Each hand-off is a lock + one variable; the consumer
takes the newest and the producer overwrites. A queue would deliver stale
frames the filter treats as current.

Runtime setup, once, after models load:

```python
gc.freeze(); gc.disable()          # 35 ms collect pause measured -> 0 after freeze
sys.setswitchinterval(0.001)       # default 5 ms GIL hold -> 1 ms
```

Run `gc.collect()` manually only when no track is active. Preallocate arrays
in the control loop.

**Display:** draw on a 640×360 copy, never the inference buffer. Measured cost
~1.3 ms per frame; at 30 fps that is ~4 % GIL duty — acceptable. If the
control-loop period jitter exceeds 5 ms with the display on, move the display
to a separate process fed by shared memory. Measure before deciding.

### 5.2 Capture

**Use MSMF, not DSHOW. This is measured, and an earlier version of this
document said the opposite.** On the C270 at 1280×720:

| backend | `set(FOURCC, MJPG)` | reported FOURCC | `CAP_PROP_FPS` | **delivered fps** |
|---|---|---|---|---|
| `CAP_DSHOW` | returns `True` | `YUY2` | 30.0 | **10.0** |
| `CAP_MSMF` | returns `False` | `""` (empty) | 30.0 | **30.4** |

DirectShow accepts the FOURCC request, silently ignores it, stays in
uncompressed YUY2 — which cannot fit 720p30 through USB 2 — and *still* reports
`CAP_PROP_FPS = 30`. Every signal it gives you is wrong, and you lose two
thirds of your frame rate without a single error. Media Foundation negotiates
the compressed mode itself, so it **refuses** `set(FOURCC)` and reports an
empty FOURCC (it hands back already-decoded BGR). Do not read that `False` as
a failure and do not "fix" it by switching back to DSHOW.

```python
cap = cv2.VideoCapture(index, cv2.CAP_MSMF)      # MSMF -- see the table above
cap.set(cv2.CAP_PROP_FRAME_WIDTH, 1280); cap.set(cv2.CAP_PROP_FRAME_HEIGHT, 720)
cap.set(cv2.CAP_PROP_FPS, 30)
cap.set(cv2.CAP_PROP_AUTO_EXPOSURE, 0.25)        # manual; convention differs by backend
cap.set(cv2.CAP_PROP_EXPOSURE, -6)               # tune: short, no bloom on the dot
cap.set(cv2.CAP_PROP_GAIN, ...)                  # tune
# Never trust CAP_PROP_FPS. Time 40 frames at startup and assert >= 25.
```

**Verify the rate at startup, per camera, every run.** Time 40 `read()` calls
and refuse to start if the delivered rate is below 25 fps. A silent drop to 10
fps triples the control-loop latency and the tracking will look like a tuning
problem for hours before anyone checks the capture.

Full measured mode table, C270 on this machine (`probe_camera.py`, 40-frame
bursts, written to `turret_vision/camera_modes.json`):

| backend | size | delivered fps | median gap | worst gap |
|---|---|---|---|---|
| MSMF | **1280×720** | **30.14** | 32.5 ms | 50.0 ms |
| MSMF | 640×480 | 30.07 | 32.0 ms | 48.2 ms |
| DSHOW | 1280×720 | 10.00 | 98.5 ms | 121.6 ms |
| DSHOW | 640×480 | 30.11 | 32.1 ms | 48.5 ms |

1920×1080 and above are rejected on both backends — 1280×720 is the camera's
ceiling, as expected. Note DSHOW is fine at 640×480: the bandwidth only runs
out at 720p, which is why this is easy to miss if you test at VGA.

Two things confirmed by the same run and worth having in hand:

- `CAP_PROP_BUFFERSIZE` is **not settable** (`set()` returns False). The
  continuous-grab thread is mandatory, not an optimisation.
- Manual exposure **does** take, via DSHOW. If MSMF's exposure control turns
  out to be inadequate on the bench, the fallback is to set exposure through a
  short DSHOW open, release it, then reopen on MSMF for streaming — UVC
  controls persist on the device across handles. Verify that on the bench
  before relying on it.
- Worst-case frame gap at 720p/MSMF is 50 ms against a 33 ms median, so the
  predictor has to tolerate an occasional missed frame. Do not treat a single
  late frame as a lost track.

**MSMF opens are slow and unreliable. Treat startup as a failure-prone step,
not a formality.** Observed repeatedly on this machine:

- `VideoCapture(1, CAP_MSMF)` on the integrated webcam (which has a paired IR
  sensor) blocked over three minutes with no error.
- The same open on the C270 took under a second on one run and over three
  minutes on the next, with nothing changed.
- **Opening two MSMF captures concurrently from two threads does not work** —
  the second never became ready within 20 s. Media Foundation's source-reader
  startup does not tolerate being raced.
- A camera whose process was killed without `release()` stays claimed, and the
  next open either blocks or returns a capture that delivers no frames. The
  symptom is `isOpened() == True` with every `read()` failing.

So:

1. **Open cameras sequentially, never concurrently.** Only the steady-state
   capture is parallel. `dual_capture_test.py` does it this way for exactly
   this reason.
2. Open in a worker thread with a ~10 s deadline; fall back to DSHOW on
   timeout, degraded rate and all, rather than letting startup wedge.
3. **Verify frames, not just `isOpened()`.** Require N successful `read()`
   calls before declaring a camera ready.
4. **Always `release()`**, including on exception and on Ctrl-C. Wrap the
   capture in a context manager or `try/finally`. A leaked handle costs you the
   next run.
5. Resolve the index by VID/PID first (`identify_cameras.py`) so you never open
   the wrong device to begin with.

Budget real time for camera startup on demo day — it is not instant, and it is
the least reliable part of the host stack.

The grab thread runs `cap.grab(); t = perf_counter(); cap.retrieve()` in a
tight loop and publishes `(frame, t)` to the slot. **This is the only way to
defeat the driver's hidden 2–5 frame buffer** — `CAP_PROP_BUFFERSIZE` is not
honoured on Windows. Timestamp at `grab()` return; that is the best available.

Lock exposure and gain. Auto-exposure changes frame timing (unpredictable
latency) and blooms the green dot into a blob.

For the wide camera, decode MJPEG on the GPU: `torchvision.io.decode_jpeg`
with `device="cuda"`. At 1920×1080 CPU decode is ~6–12 ms per frame and holds
the GIL — worth moving off the CPU, but measure first; it may fit.

**Run the wide camera at 1920×1080. Do NOT downscale it to 720p.** An earlier
revision of this document suggested 720p to save bandwidth. That is backwards
on this module — measured:

| backend | size | delivered fps | median gap | worst gap |
|---|---|---|---|---|
| MSMF | **1920×1080** | **30.31** | 32.5 ms | 46.1 ms |
| MSMF | 1280×720 | **9.01** | 107 ms | **277.8 ms** |
| MSMF | 640×480 | 29.77 | 32.1 ms | 48.5 ms |
| DSHOW | 1920×1080 | 4.97 | 204.8 ms | 244.0 ms |
| DSHOW | 1280×720 | 9.93 | 97.5 ms | 115.2 ms |

1080p is this module's native compressed mode. 720p apparently is not in its
MJPEG list, so it falls back to uncompressed and starves — **a 70 % frame-rate
loss for asking for fewer pixels**, with a worst-case gap of 278 ms, nearly
nine frame periods. If you genuinely need to cut pixels, drop straight to
640×480 (29.8 fps), which is a real compressed mode. Never assume a smaller
frame is a faster one; probe it.

Same rule as the C270: **verify the delivered rate at startup and refuse to
run below 25 fps.**

#### USB: cameras on separate NATIVE ports. This is not advisory.

Cameras on **separate USB root ports**; Pico on a third if possible. **Never
run both cameras through one hub or USB-C splitter.**

This was hit for real during bring-up. On the dev laptop both cameras were
behind a USB-C → 3× USB-A splitter — a single hub, so every port shares one
upstream link. Result: each camera worked perfectly alone (narrow 1280×720,
wide 1920×1080), but the second one to start **failed outright**, with
`ERROR_DEVICE_NOT_CONNECTED` (`0x8007048F`) from MSMF.

That error is a liar. The device is present, enumerated, and works alone. A
UVC camera reserves isochronous bandwidth for its whole stream at start-up, and
when there is none left the start is simply refused. Expect to waste an hour on
this if you do not recognise it.

**Diagnosis:** compare `LocationInfo` strings (`identify_cameras.py`, or Device
Manager → View → Devices by connection). Two cameras sharing a path prefix
share an upstream link. On the dev laptop both read `...0014.0000.003.x` —
same branch. The integrated webcam was on `...006`, a different one.

**Fix:** separate native ports. The GPU host has native USB-A, so this specific
failure probably does not reproduce there — **but verify it, do not assume it.**
Run `turret_vision/dual_capture_test.py` on the GPU host before anything else;
it opens both cameras, measures them together, compares against the solo rates
in `camera_modes.json`, and on failure walks a fallback ladder to report what
*does* coexist. A laptop result does not transfer.

**Lowering the resolution does not rescue a shared hub.** Tested on the dev
laptop: with the narrow camera streaming, the wide camera refused to start at
1920×1080, at 640×480, *and* at 320×240. A 320×240 stream is a few Mbit/s, so
this is not bandwidth arithmetic you can duck under — the splitter simply will
not carry two concurrent UVC streams at any size. Cheap USB-C hubs often have a
single transaction translator, which serialises high-speed traffic badly enough
that the second isochronous stream never establishes.

**So there is exactly one fix: separate native ports.** Resolution fallbacks
are worth trying (the test walks them automatically) because on a *different*
topology the failure may genuinely be marginal bandwidth — but do not plan
around them. If the demo machine cannot give each camera its own native port,
that is a hardware problem to solve before demo day, not something to tune
around in software.

Never put the wide camera at 1280×720 in any case — on that module it is both
slower and uncompressed.

### 5.3 Detector

- **Model:** Ultralytics YOLO, nano or small (YOLO11n / YOLOv8n). Start from
  COCO weights (already knows `bird`, `airplane`, `person`).
- **Classes:** `drone`, `bird`, `plane`. Faces come from a separate detector
  (below) so you do not need face labels in your training set.
- **Input:** the **full 1280×720 narrow frame at `imgsz=1280`**. At 30 fps a
  4070 runs a nano model at that size in a few ms. No ROI logic needed for the
  demo; it stays native resolution. (Add ROI cropping later only if you
  upgrade to a fast camera and inference becomes the limit.)
- **Wide camera:** `imgsz=1280` on a downscaled frame is fine — it only
  searches. Run it at 10 fps while a track is active, 30 fps when searching.
- **Export:** `model.export(format="engine", half=True, imgsz=1280)`. Load the
  `.engine`. 2–3× over PyTorch.
- **Confidence:** 0.35 to *propose*, then the gate (§5.4) decides.

**Face detector:** OpenCV's built-in **YuNet** (`cv2.FaceDetectorYN`). No
training, fast, runs on the wide camera every frame. Its output drives the
laser inhibit. Do not substitute a person detector — a person detector fires
on the hand holding the drone and the laser never fires.

#### The C270 has had its IR-cut filter removed — this changes the detector plan

Confirmed by the builder, invisible in any spec sheet, and it undercuts two
assumptions above.

- **COCO weights were trained on IR-cut imagery.** With the filter gone the
  sensor responds well past 700 nm, near-IR bleeds into all three channels, and
  colour stops being photometrically meaningful. This is a genuine domain
  shift, not a nuisance — expect degraded confidence straight out of the box.
  **Fine-tuning on frames from this camera moves from "most valuable" to
  "required".** Item 1 below is now the critical path.
- **Nothing may gate on colour.** Drone-vs-bird colour cues and green-channel
  laser-dot detection both get much weaker. Shape and motion still work.
- **Re-focus the C270 and verify sharpness at 2–5 m before any calibration.**
  Removing ~1 mm of filter glass shortens the optical path and shifts the focal
  plane. The lens holder is accessible (it has been opened already), so this is
  adjustable. It matters beyond looking nice: a soft image inflates bounding
  boxes, which biases apparent-size range **short** and silently corrupts the
  parallax correction. Do this first — every pixel measurement downstream
  depends on it.
- **Lock exposure and gain.** Room lighting and daylight are NIR-rich, so
  highlights bloom and auto-exposure hunts. Already required for latency
  reasons; now doubly so.

**The upside is real.** The board's IR LEDs (GPIO14) now do something. Active
NIR illumination lights a black drone in a dim room, is invisible to
spectators, and carries no laser-safety burden. If the demo room is dim or the
drone is low-contrast against the crowd, this is the lever to pull — and it is
already wired. Capture the training set **with the IR LEDs in whatever state
the demo will use**, or the fine-tune is on the wrong domain again.

**Training data, in order of value:**
1. **200–500 frames of the actual drone, held by a hand, in the actual room,
   through the filter-removed C270.** Label with any box tool; bootstrap boxes
   from COCO weights and correct them. This matters more than everything below
   combined, and the filter removal is why.
2. Drone-vs-Bird Detection Challenge dataset — exists for exactly this
   confusion.
3. Anti-UAV / Anti-UAV410; Roboflow Universe drone sets.
4. Augment with random erasing (hand occlusion) and motion blur.

### 5.4 Track and gate

Single target. Associate the detection nearest the Kalman prediction within a
gate of 3σ (start: 60 px). No ByteTrack needed for one target — add it only if
multiple drones ever appear.

| state | enter | leave |
|---|---|---|
| SEARCH | start; TRACK lost | drone detected in wide → slew toward it |
| ACQUIRE | drone detected in narrow | 5 consecutive frames → TRACK; 3 misses → SEARCH |
| TRACK | confirmed | 10 consecutive misses → COAST |
| COAST | track lost | hold last velocity 150 ms, decay to 0 over 300 ms; **laser off immediately** |

Laser may be on only in TRACK, and only when the face inhibit is clear and
`|e| < 25 px`.

### 5.5 Pixel Kalman with adaptive Q

State `x = [u, v, u̇, v̇]`, measurement `z = [u, v]` = bbox centre.

```
F(dt) = [[1,0,dt,0],[0,1,0,dt],[0,0,1,0],[0,0,0,1]]
H     = [[1,0,0,0],[0,1,0,0]]
Q(dt) = q · [[dt⁴/4, 0, dt³/2, 0],[0, dt⁴/4, 0, dt³/2],[dt³/2, 0, dt², 0],[0, dt³/2, 0, dt²]]
R     = σ_m² · I₂         σ_m = 3 px to start
```

`dt` from the capture timestamps, never assumed. Predict for the control law
to `t_now + L` (§6.1).

**Adaptive Q:** innovation `ν = z − H·x⁻`, `S = H·P⁻·Hᵀ + R`,
`NIS = νᵀ S⁻¹ ν`. If `NIS > 9.21` (χ², 2 dof, 99 %): `q ← min(q·8, q_max)`.
Every frame: `q ← q_base + 0.85·(q − q_base)`. Start `q_base` so that
`√q ≈ 3 m/s²` expressed in px/s² (`3 · f / R` ≈ 1400 px/s² at 3 m), `q_max`
= 30× that. Tune on a recording of someone jinking the drone by hand until
the innovation sequence looks white.

**Aim-point stabiliser (occlusion by the hand):** track bbox area alongside
the centre. If area drops >30 % in one frame while the centre shifts toward
the surviving edge, hold the previous centre's offset from that edge instead
of re-centring on the remnant. Release when area recovers within 20 %. Also
**bias the aim point up by 15 % of box height** — the hand is below the drone.

**Rolling-shutter bias:** the C270 reads out over ~20 ms, so a moving target's
centroid is displaced in the direction of motion by roughly `k·v̂` with
`k ≈ 0.010 s`. Subtract it from each measurement. Calibrate `k` once by
panning the turret past a static object at a known step rate and measuring the
apparent shift. Drop this if the camera is upgraded to global shutter.

### 5.6 The laser dot as the goal

532 nm on a black airframe is high contrast. Each frame, in a 60×60 window
around `g(R)`:

```
mask = (G − max(R,B)) > τ     with locked exposure, τ ≈ 60 to start
```

Accept a blob of 3–40 px area with roundness > 0.6. If found, **use its
centroid as `g`** for this frame — the loop then measures its own miss and
every modelling error cancels. If not found, use `g(R)`. Never gate anything
on the dot being visible; it is opportunistic, as the human said.

**This mask is chroma-based, and the C270 has no IR-cut filter.** 532 nm is
still strongly G-dominant, so the test should survive — but near-IR passes
every Bayer filter roughly equally, so NIR-lit surfaces go grey and the whole
scene desaturates, shrinking the margin. Two consequences:

- **Retune `τ` on real frames.** The τ ≈ 60 starting point assumes an IR-cut
  sensor; it is a guess here.
- **The IR LEDs make this worse, not better.** Under NIR illumination the black
  airframe goes bright grey, and `G − max(R,B)` on a bright grey background is
  small — exactly where the dot has to be found. If you use the IR LEDs for
  detection, either pulse them off on alternate frames for dot-finding, or add
  a local-brightness-peak term so the test does not rest on chroma alone. The
  dot is both the greenest *and* the brightest thing in a 60×60 window; use
  both.

Since the dot is opportunistic, none of this is fatal — worst case you fall
back to `g(R)` more often. Just do not assume the mask works because it works
on a normal webcam.

### 5.7 Control law

```
p̂  = predicted target pixel at t_now + L
p̂̇  = predicted pixel velocity
e   = p̂ − g
if |e| < 1 px: e = 0                           # deadband on the P term only
ω   = J_inv @ (K·e + p̂̇)                      # ω = [ωA, ωB] motor steps/s
ω   = clip(ω, ±MAX_RATE)
send f"vel {ωA:.0f} {ωB:.0f}"
```

`K` in 1/s. Start **K = 2.0**. Raise until the response to a step (jog the
turret, watch the error decay) starts to overshoot, then back off 30 %. With
`L ≈ 60 ms` expect to land around K = 3–4.

Send `vel` on every frame, immediately after the detection lands. The Pico
holds the rate between frames — that is what keeps the beam moving with the
drone at 30 fps. Send `vel 0 0` on any transition out of TRACK; the watchdog
covers a host crash.

### 5.8 Serial

`pyserial` at any baud (USB CDC). One writer thread, one line per command,
read the `ok` reply. Keep the writer isolated so a USB stall cannot block the
control thread — the control thread writes into a 1-deep slot, the serial
thread drains it. Measure `vel`→`ok` round trip; expect 1–3 ms.

### 5.9 Spectator display

Read from the control thread's published state. Show: the narrow view with
bbox, predicted point, goal pixel, the dot if seen; the wide view with all
detections and faces; a large laser state indicator — `SEARCH` / `ACQUIRE` /
`TRACK` / **`INHIBITED — face`** / `FIRING`; and the adaptive-Q level as a bar
so a jink is visible. The `INHIBITED — face` banner is the demo moment. Keep
it to 30 fps and 640×360.

---

## 6. Calibration — the four empirical constants

Do these in order. Each takes minutes. Record the numbers in `config.py`.

### 6.1 Latency `L`

Wire an LED to a spare Pico GPIO (18 or 22) and point it at the narrow camera.
Add a `blink` command. From the host: send `blink`, timestamp; find the first
frame whose ROI brightness jumps, take its capture timestamp. `L` = the
difference, averaged over 50 trials; also record the spread.

Expect 50–70 ms with the grab thread; 90–160 ms without it. If you see the
latter, the grab thread is not doing its job. Repeat with the display on and
off; the difference is your display cost.

### 6.2 Backlash and preload — **MEASURED: 0.57 deg**

Measured 2026-09-16 with the payload IMU, by hysteresis loop: sweep pitch up
in 0.5 deg steps recording absolute tilt from the accelerometer, sweep back
down, fit both branches, and take the gap between them.

```
up branch     slope 1.124 deg tilt / deg commanded    resid rms 0.197
down branch   slope 1.306                             resid rms 0.324
gap between branches                                  0.694 deg of tilt
BACKLASH = gap / slope                                0.571 deg of payload
                                                      ~12 motor microsteps at 1/16
```

**Treat it as 0.57 +/- 0.15 deg.** The two branches disagree on slope (1.124
vs 1.306) and the residuals are large next to the gap, which should not happen
in a clean loop -- most likely the accelerometer is still reading some
tangential acceleration despite the settling delay, or the sweep is short
enough that rotor detent biases the branches differently. A longer sweep with
more settling would tighten it.

**What it means for you.** This is well above the 0.16-0.46 deg that
`HARDWARE_NOTES.md` estimated from PA12 tooth clearance, so the estimate was
optimistic. At 3 m, 0.57 deg is **30 mm of beam wander on every direction
reversal** -- an order of magnitude past the 2.55 mm step resolution. So
**backlash, not resolution, sets pointing accuracy on a reversing target**, and
a hand-held drone reverses constantly. Budget for it; do not assume the step
size is your error floor.

`PRELOAD_STEPS` should therefore be about `1.2 x 12 = 14` motor microsteps.

Note this could not be measured at all before the IMU went on: there is no
encoder, and you cannot see lost motion using the same counter that commanded
the motion.

Re-measure on the day. PA12 swells with humidity.

#### The original procedure, for reference

Two-move test from vel mode:

1. `vel 100 100` for 2 s (both motors, same sign → pitch), then `vel -100 -100`.
2. In the narrow camera, count frames from the reversal until a static scene
   feature begins moving the other way. `lash_steps = 100 · Δt`.
3. Repeat opposite-sign (yaw). Repeat both twice. Take the worst.

Set `PRELOAD_STEPS = round(1.2 · lash_steps)`. On startup, after homing:
`preload <PRELOAD_STEPS>`. Re-run the two-move test; residual lash should be
0–2 steps. If it is still >3, enable reversal compensation in the 200 Hz loop:
on a sign change, add `residual` extra steps at `MAX_RATE` before resuming.

Measure on the day. PA12 swells with humidity.

### 6.3 The image Jacobian `J`

Static scene (or the drone held still). Note a distinct feature's pixel
position `p₀` in the narrow camera.

1. `move pan 200` (Motor A). Measure `p₁`. `move pan -200`.
2. `move tilt 200` (Motor B). Measure `p₂`. `move tilt -200`.

```
J = [[ (p₁−p₀).u/200, (p₂−p₀).u/200 ],
     [ (p₁−p₀).v/200, (p₂−p₀).v/200 ]]        px per step
J_inv = inv(J)
```

Use 200 steps so the shift is tens of pixels but the feature stays in frame.
This `J` already contains the belt, the differential, the joint order, the 11°
axis tilt, the camera's focal length and the sign of everything. If the demo's
yaw range exceeds ±25°, repeat at the extremes and interpolate; otherwise one
`J` at the centre is fine.

**Signs:** if the turret runs away from the target instead of toward it, a
column of `J` has the wrong sign. That is finding 5 showing up. Fix it in `J`,
not in the loom.

### 6.4 Goal pixel `g(R)`

Point at a flat wall. Enable the laser. At two measured distances `R₁`, `R₂`
(say 2.0 m and 4.0 m), find the dot's pixel `g₁`, `g₂` in the narrow camera.
Fit per axis:

```
g(R) = g_∞ + c / R          two points → g_∞ and c
```

That is the parallax correction, calibrated without knowing `f` or the
offsets.

**This is also why the C270's 90° rotation and its unknown sign do not block
you.** Fitting `g(R)` per axis from two measured points determines the
direction and magnitude of the parallax empirically — rotation, sign, axis swap
and lens depth all fall out of the fit. The sign ambiguity only bites if
someone hard-codes the correction from the CAD numbers instead of calibrating.
**Do the calibration; do not derive `g(R)` analytically.**

Range `R` at runtime from **apparent size**:
`R = f · W_real / w_px` with `W_real` = the drone's real width and `f` from
a single measurement (known-width object at known distance). A 20 % range
error costs ~3–4 px at 3 m; apparent size is better than that.

Stereo range via the wide camera is an upgrade, not a requirement.

---

## 7. Build order with acceptance tests

| M | build | passes when |
|---|---|---|
| **M0** | Deploy the existing suite; `safe` passes; `move pan 400` / `move tilt 400` move the right physical motors | `safe` all PASS/INFO/WARN, no FAIL |
| **M1** | Firmware vel mode (§4) | hardware test in §4.7 passes; host tests pass |
| **M2** | Latency `L` (§6.1), backlash + preload (§6.2) | `L` known with spread; residual lash ≤2 steps |
| **M3** | Capture threads + display; **`J` calibrated** (§6.3) | 30 fps sustained on both cameras; `L` unchanged with display on |
| **M4** | Control loop with a **hand-clicked pixel** as the target (no detector) | click a static point → laser lands on it within 2 frames and stays; move the *turret* by hand → it returns |
| **M5** | Same, with the target moved by hand (click follows a template tracker) | laser follows a hand-moved marker at 0.5 m/s with <15 mm error, no visible stepping |
| **M6** | Detector fine-tuned; face detector; gate | tracks the real drone, held; face inhibit fires reliably, hand does not trip it |
| **M7** | Adaptive Q, occlusion stabiliser, `g(R)` (§6.4), dot override | a jink re-acquires within 5 frames; laser stays on the airframe with a hand over a third of it |
| **M8** | Wide→narrow handoff; rehearsal; hard-negative retrain | end-to-end demo from cold start |

**M4 and M5 are the ones to protect.** They prove the loop with nothing
learned in it. If M5 does not hold, no detector will save M6. Do not skip to
M6 because it is more interesting.

---

## 8. Tuning notes

- **Jitter, not lag, is what looks bad.** If the beam wanders while the target
  is still, lower `K` or raise `R` (measurement noise) before touching `q`.
- **Lag on a fast move** → `L` is under-estimated, or `q_base` is too low.
  Re-measure `L` first.
- **Overshoot on a jink** → `q_max` too high or decay too slow. Halve `q_max`.
- **Laser lands beside the target consistently** → `g(R)` is off. Re-do §6.4,
  or the range estimate is wrong (check `W_real`).
- **Stair-stepping / visible ticks** at low speed → `ACCEL` too high for the
  step rate, or the Pico timer is missing ticks. Check for allocation in the
  callback.
- **Dead zone after reversals** → preload lost. Re-run `preload`. It drifts
  slowly if the two motors' rates differ for long periods.
- **Runaway** → a sign in `J` is wrong. Stop, fix, redo §6.3.

---

## 9. What would surprise you if I did not say it

- `pan`/`tilt` in the firmware are **not** pan and tilt. They are Motor A and
  Motor B of a differential. Both move for any single-axis motion.
- The two motors turn **opposite directions** for the same command sign. `J`
  absorbs it. Do not "fix" the wiring.
- The C270 through OpenCV with `CAP_DSHOW` silently delivers 10 fps instead of
  30 at 720p while reporting 30 — use `CAP_MSMF` and verify the real rate.
- The C270 through OpenCV silently adds 2–5 frames of latency unless you use
  the grab-loop pattern.
- A person detector will keep the laser off during the demo. Use faces.
- `gc.collect()` measured **35.6 ms** on a modest heap. Freeze it.
- The Pico's STEP pad must be claimed for PIO every time an SM is activated;
  MicroPython does it only at construction.
- MicroPython cannot build an exception class from two built-in bases — the
  existing code uses a `usage` flag instead; keep that pattern.
- The magnetometer is decoration. The gyro and accelerometer are useful.
- Never plug or unplug a motor with VMOT live.

---

## Appendix 0 — every command on the board

Serial console, 115200, USB CDC. `gui_server.py` wraps this as HTTP on :8420
(`POST /api/cmd {"cmd": "..."}`, `GET /api/state`); `sim/serve.py` proxies that
same-origin on :8500 and starts the controller on demand. Talk to whichever
suits you -- it is one console underneath.

**Tracking (what your loop uses)**

| command | does |
|---|---|
| `vel <A> <B>` | signed motor rates, steps/s. Enters velocity mode. |
| `pvel <pitch> <yaw>` | signed payload rates, deg/s. **Replies `ok <pitch> <yaw>`.** |
| `velmode off \| status` | leave velocity mode / report rate, ticks, trips |
| `state` | one line of JSON: pose, per-axis mode/rate, velocity block, outputs |

**Payload motion (setup, homing, by hand)**

| command | does |
|---|---|
| `aim <pitch> <yaw> [dps]` | absolute payload move (blocking, ramps to a stop) |
| `dmove <dpitch> <dyaw>` | relative payload move |
| `pitch <deg>` / `yaw <deg>` | pure pitch / pure yaw |
| `level [tol]` | **drive to true level using the IMU**, then set the datum |
| `dzero` | set this pose as payload zero |
| `sethome [p y]` / `home2` | store a datum / return to it |
| `limits` | travel limits, current pose, clamp policy |
| `diff` | resolution, ratio, signs |
| `dchar` | characterise the differential (manual, watch it) |
| `dsign pitch\|yaw\|A\|B` | flip a sign for this session |

**IMU**

| command | does |
|---|---|
| `imu` | status, live rate and tilt |
| `imu cal` | gyro zero-rate calibration -- **payload must be still** |
| `imu watch` | streaming rate + tilt |

**Peripherals, motors, diagnostics**

| command | does |
|---|---|
| `laser on\|off\|pulse <ms>` | gated by `LASER_ENABLED` and Finding #7 |
| `laser pwm [hz] [duty]` | pulse train, default 15 Hz -- see §1.5c |
| `ir` / `fan` | same switched-output family |
| `enable\|disable <axis>` | energise / release coils (`pan`\|`tilt`\|`both`) |
| `ms <axis> <div>` | microstepping; **use 16** |
| `move\|deg\|step <axis> ...` | single-MOTOR moves -- not payload axes |
| `accuracy <axis>` | out-and-back lost-step check |
| `home <axis>` / `endstops` | endstop homing / live monitor |
| `safe` / `motion` | no-motion test suite / motion suite |
| `status` / `pins` / `cfg` / `findings` / `wiring` | information |
| `stop` | disable everything, drop all outputs |

**Remember `pan` is MOTOR A and `tilt` is MOTOR B.** Neither is a payload axis;
driving one alone moves the payload diagonally. Use the payload commands.

### Files

```
turret_test/
  stepper.py      PIO step generation, Axis, coordinated_move, VelocityLoop
  kinematics.py   differential transform, Platform, travel limits, home
  imu.py          GY-85 driver (gyro / accel / mag)
  peripherals.py  switched outputs, laser interlock + PWM, I2C, sensors
  cli.py          the console -- every command above
  config.py       all tunables. Read this before changing behaviour.
  pinmap.py       hardware truth from copper. Do not edit.
  tests/host_test.py   205 tests, runs on a PC with no hardware
sim/
  wrist-ik.html   3D viewer, closed-loop velocity drag, collision + clearance
  serve.py        serves the viewer, proxies /api/*, starts the controller
  export_mesh.py  CAD -> mesh + measured joint axes
turret_vision/
  identify_cameras.py  USB identity of each camera (indices are not stable)
  probe_camera.py      real delivered fps per mode per backend
  dual_capture_test.py both cameras at once -- USB bandwidth check
  head_geometry.py     laser/camera offsets, parallax, stereo maths
```

---

## Appendix A — kinematics, for understanding only

With motor angles `θ_A, θ_B` and belt reduction `N = 2.3077`:

```
pitch = (θ_A + θ_B) / 2N          θ_A = N·(pitch + yaw)
yaw   = (θ_A − θ_B) / 2N          θ_B = N·(pitch − yaw)
```

Signs to be confirmed empirically (the IMU three-move test in
`VISION_BUILD_PLAN.md` §2). Pitch is the outer joint; the yaw axis rides on
the carrier and is 11° off nominal +Y in the CAD rest pose. The two axes
intersect at CAD (0, 28, 0). For a pitch-outer wrist with boresight along +x
the closed-form pointing inverse is `θ_pitch = atan2(−u_z, u_x)`,
`θ_yaw = atan2(u_y, √(u_x²+u_z²))`. None of this is used by the servo loop.

## Appendix B — if the narrow camera is upgraded

Target: global shutter, ≥90 fps at native resolution, USB 3 uncompressed, UVC,
manual exposure, ≥1280 px wide, colour. **AR0234** class (Arducam / ELP /
e-con See3CAM_24CUG). Then: drop the rolling-shutter bias term; run inference
on an ROI crop only if it becomes the bottleneck; expect manoeuvre response to
improve ~3× and the honest pitch to include evasive targets.

## Appendix C — the sim

`https://claude.ai/code/artifact/3c0bc01c-0d6b-4e6c-ab59-a40f6d2a129b` — the
wrist's real CAD geometry with the differential kinematics live. Drive the
motor sliders to see which motion is pitch and which is yaw.

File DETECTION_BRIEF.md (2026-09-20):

# Detection & training brief — Laser Turret

**For:** whoever is building the perception layer, and the assistant helping them.
**From:** the hardware side. Written 2026-09-17.
**Showcase:** 22 September 2026.

---

## 0. Read this first — your job includes disagreeing with this document

This brief was written by someone who **has not built the perception layer and
has not tested most of what follows**. It is a considered starting point, not a
specification. Several decisions in it are reasoned from first principles
rather than measured, and §9 lists exactly which ones.

**Before executing any of this, audit it.** Specifically:

- Is the training approach in §5–§6 actually the right one, or is there a
  better path given five days?
- Is the detection approach in §4 sound, or is it solving the wrong problem?
- Are the numbers (frame counts, sampling rates, model sizes) defensible, or
  are they folklore?
- Is anything here going to waste a day that cannot be recovered?

**Start with §10.** Survey the actual machine before planning around it — two
of the worst failures on this project so far were machine-level (USB topology,
and a serial read that silently cost 150 ms per command), not code-level.

If you think a section is wrong, **say so before doing it**. A confident
objection now is worth more than a completed task that turns out to be the
wrong task. The deadline is tight enough that one wasted day is most of the
remaining budget.

Assume the author was wrong about at least one important thing. Find it.

---

## 1. What this system is, in one paragraph

A pan/tilt turret carries two cameras and a 5 mW green laser. It has to find a
drone held in a person's hand, 2–5 m away, indoors, in a room with people in
it, and keep the laser on the drone while the person moves it around. The
mechanical and firmware side is built and documented in `AGENT_HANDOFF.md` —
**read that before this**; it has the control API, the measured constants, and
the things that will surprise you. This brief covers only the part that is not
built: getting a detector that works on this specific footage.

## 2. What is already done (so you don't rebuild it)

- **Motion, firmware, control loop.** Velocity mode is built and measured —
  200 Hz loop, 43 ms host round trip, watchdog, travel limits. The API is
  `AGENT_HANDOFF.md` §4.8. You should not need to touch firmware.
- **A working 3D viewer** (`sim/wrist-ik.html`) that drives the real turret
  with a closed-loop velocity scheme. It is a reference implementation of the
  control side you can read and steal from.
- **Cameras characterised.** Use the **MSMF** backend on Windows, never DSHOW
  (measured: DSHOW caps the C270 at 10 fps while reporting 30). The wide camera
  is 1920×1080 and is *slower* at 720p. Details in `AGENT_HANDOFF.md` §5.2.
- **Backlash measured at 0.57°**, which is bigger than the step resolution and
  matters for how tightly you can expect to hold aim on a reversing target.

## 3. The hardware you are pointing at

| | |
|---|---|
| narrow camera | Logitech C270, 1280×720 @ 30 fps, **mounted rotated 90°**, **IR-cut filter removed** |
| wide camera | generic 120° UVC module, 1920×1080 @ 30 fps |
| laser | 532 nm, 5 mW, on the payload between the cameras |
| target | black quadcopter, ~283 mm diagonal, **held in a hand** |
| compute | RTX 4070 on the demo machine |

**Two of those matter more than they look.**

The C270's **IR-cut filter has been removed**. Near-infrared now reaches all
three colour channels, so colour is not photometrically meaningful and every
pretrained model you might use was trained on IR-cut imagery. This is a real
domain shift, and it is the main reason this brief argues for capturing your
own data.

The C270 is **mounted rotated 90°**, so its effective horizontal field is
28.8°, not 49°. Frames come out of the camera rotated. Decide early whether you
rotate frames (costs a copy per frame) or carry the rotation in your geometry
(free, but you must be consistent). The hardware side carries it in geometry.

## 4. The detection problem, and why public models disappoint

At 3 m the drone is about **132 px wide** in the narrow camera — roughly 10% of
frame width. That is a **large, close object**.

Every public drone dataset is the opposite: small drones against sky, because
that is the counter-UAS problem people fund. Two concrete examples that were
evaluated and rejected:

- `doguilmak/Drone-Detection-YOLOv7` — no metrics, no licence, no resolution
  stated, and the dataset explicitly keeps drones small.
- `FilippTrigub/yolov11x-drone-finetuned` — well documented (MIT, real
  metrics), but 56.8M parameters, recall 0.606, mAP50-95 0.279, single class
  with no `bird`, and trained on outdoor flight footage.

Neither has seen: a large close drone, indoor clutter, a hand partly occluding
it, or IR-contaminated colour.

**Suggested approach — challenge it if you disagree:**

1. **Start with YOLO-World** for zero-shot, so you have *something* detecting
   on day one while data collection happens:
   ```python
   from ultralytics import YOLO
   m = YOLO("yolov8s-worldv2.pt")
   m.set_classes(["drone", "quadcopter"])
   m.save("drone-world.pt")      # embeds vocabulary, drops the text encoder
   ```
   Try several prompts on real footage; which one fires is empirical.
2. **Use it to pre-label your own captured frames.**
3. **Fine-tune YOLO11n** on those frames. This is the step that actually makes
   it work.

The claim underlying all of this: *300 frames of your drone in your room beats
17,000 images of drones against sky.* **That claim is not measured. Test it** —
if zero-shot turns out to work well on your footage, skip the fine-tune and
spend the days on the control integration instead.

### Considered and rejected — overturn these if you disagree

**SAHI (Slicing Aided Hyper Inference).** Wrong tool here, on two counts. It
exists to find *small* objects in *large* images — satellite and aerial work,
where a target is a few pixels in a 4K frame. This drone is ~10% of frame
width, already large, so slicing finds nothing a whole-frame pass misses. And
it runs inference once per tile, so N slices means N forward passes; its own
documentation says it is not intended for real-time use. Since end-to-end
latency sets the control loop's gain ceiling, multiplying inference cost is the
one trade that cannot be afforded. It would be the right call for drones at
50 m against sky. Not for one in someone's hand at 3 m.

**A larger model (YOLO11x, the 56.8M-parameter drone checkpoint).** Same
reasoning: accuracy bought with latency is a poor trade when latency caps the
control bandwidth. Once fine-tuned on in-domain frames, a 132-px object against
a fixed indoor background does not need a large model.

## 5. Capture protocol — this determines your accuracy, not the model

You will record video of people holding the drone in front of the cameras.
**The variation in that footage matters more than the amount of it.** 300
near-identical frames teach almost nothing.

Deliberately vary:

- **distance** — 2, 3, 4, 5 m
- **occlusion** — different grips, covering different parts of the airframe.
  This is the hardest case and the one the demo actually contains.
- **drone orientation** — all three axes, including nose-on where it presents
  its smallest silhouette
- **background** — cluttered and plain parts of the room, people moving behind
- **motion** — record while moving, so you capture the motion blur the live
  system will see
- **lighting** — the range the actual demo room will have

**Capture negatives.** Frames with people holding *nothing*, and holding other
objects — a phone, a bottle, a mug. Without these the model learns "person
therefore drone", which fails in a room full of spectators.

**Use both cameras.** Their optics differ enough (49° vs 105°, different
distortion, one with its IR filter removed) that a model trained only on the
C270 may not transfer to the wide camera.

**You do NOT need to calibrate the cameras first.** Calibration buys stereo
range; it has nothing to do with labelling boxes. Do it later, in parallel.

**Match the live pipeline.** If you record H.264 to a drive and train on frames
extracted from it, you train on H.264 artifacts while inference sees
MJPEG-decoded frames. Capture stills through the same OpenCV path the live
system uses, or record MJPEG.

## 6. Frame sampling — and the mistake that invalidates your metrics

**Sample at 1–2 Hz** — roughly every 15–30th frame at 30 fps. Consecutive
frames are near-duplicates and teach nothing new.

**The rule that actually matters: split by clip, never by frame.** All frames
from one recording go entirely to train or entirely to validation. If
near-duplicate frames land on both sides, your validation score measures
memorisation and will look excellent while the model fails live. This is the
most common way people fool themselves, and it is silent.

Better than fixed-interval sampling: keep a frame only when it differs
sufficiently from the last kept one (frame difference or perceptual hash above
a threshold). This naturally keeps more frames during motion.

**Is 1–2 Hz right? Is 300 frames enough?** Both are heuristics. If you have a
better-grounded number, use it.

## 7. Labelling — do not build a tool

The hardware side sketched a custom labelling suite. **That was probably a
mistake and you should push back on it.** CVAT, Label Studio, Roboflow and
FiftyOne all already do model-assisted pre-labelling, box editing, reject,
keyboard-driven review, and YOLO-format export. Roboflow does the whole
upload → auto-label → correct → export → train loop in a browser.

Building a labelling tool with five days left is the most expensive way to
spend them.

Whatever tool you use, make sure it supports three distinct outcomes, because
they are not the same thing:

- **no drone present** — a valuable negative, keep the frame
- **frame unusable** — blur, drone half out of frame — discard it
- **model missed it** — the labeller must be able to draw a box from scratch

One idea worth keeping: **sort frames by model confidence and review the
least-confident first.** If you run out of time, you will have labelled the
frames that mattered rather than a random half.

## 8. Laser safety — this part is not negotiable

The demo points a laser at people holding a drone. Their heads are near their
hands. Treat this as a safety system, not a feature.

**Make the logic fail-closed.** "Fire unless a face is detected" is fail-open:
a dropped frame, a missed profile, or a model hiccup and the beam fires into an
unknown scene. **"Fire only when the aim point is inside a confirmed drone
box"** is fail-closed — any detection failure turns the beam off. Same models,
opposite failure mode. Make the drone lock the *permission*, and head detection
a veto on top of it.

**Heads, not faces.** Someone turned away is invisible to a face detector and
can turn round in ~0.3 s. Suggested approach, no training required:

- **`YOLO11n-pose`** — COCO-pretrained, nano speed, 17 keypoints including
  nose/eyes/ears. It estimates head position from body configuration, so it
  works from behind.
- **COCO `person` detection** as a backstop — the most reliable class in the
  dataset, fires from any angle; the head is roughly the top 15% of the box.
- **YuNet** (`cv2.FaceDetectorYN`) as a third signal when a face *is* visible.

Union all three. Note the subtlety: inhibit on the **head region only**, not
the whole person — the drone is in their hands, so a whole-person inhibit means
the laser never fires at all.

**Size the inhibit margin, don't guess it.** It must cover detection latency
plus turret slew plus human motion. At 3 m a head is ~25 cm ≈ 4.8°, so expect
the margin to be several head-widths. Compute it from the measured latency `L`
(`AGENT_HANDOFF.md` §6.1) once that exists.

**A hardware hazard worth raising with the hardware side:** cheap 532 nm DPSS
modules often emit substantial 1064/808 nm IR because the blocking filter is
omitted. Invisible light triggers no blink reflex, so the body's own protection
does not operate. This should be measured or an IR-blocking filter fitted. No
amount of head detection substitutes for it.

## 9. Things the author is NOT confident about — challenge these first

Listed honestly, worst-founded first. If you can cheaply test one, do that
instead of trusting it.

1. **That zero-shot YOLO-World will fire on this drone at all.** Completely
   untested. Ten minutes with real footage settles it, and the answer changes
   the plan.
2. **That 300 frames is enough.** Rule of thumb. Could be 150, could be 800.
3. **That fine-tuning from COCO beats fine-tuning from a drone-pretrained
   checkpoint.** Argued from "the drone checkpoints are out-of-domain", but
   starting from 17k drone images might still transfer better. Worth one
   experiment if time allows.
4. **That the IR-filter removal hurts pretrained models as much as claimed.**
   Reasoned, not measured. Easy to check: run any COCO model on a filtered and
   an unfiltered frame of the same scene.
5. **That `YOLO11n-pose` reliably locates heads from behind.** Plausible,
   unverified.
6. **That nano at `imgsz=1280` is fast enough on a 4070** alongside capture,
   pose, tracking and display. `AGENT_HANDOFF.md` asserts a few ms. Measure it.
7. **That 1–2 Hz is the right sampling rate.**
8. **Whether to train one model on both cameras or one per camera.** Untested
   either way.
9. **Whether the demo narrative needs a `bird` class at all.** It is in the
   story ("confirms it isn't a bird") but may be pure narrative — COCO already
   knows `bird` if you need it.

## 10. Survey the machine before you plan around it

Do this first. It takes ten minutes and it changes what is worth attempting.
Several of the decisions in this brief assume performance that your specific
machine may or may not have, and two of the biggest failures on this project so
far were machine-level rather than code-level.

### What to collect

```bash
# GPU, driver, VRAM
nvidia-smi
python -c "import torch; print(torch.__version__, torch.version.cuda); print(torch.cuda.get_device_name(0), torch.cuda.get_device_capability(0)); print('VRAM GB', torch.cuda.get_device_properties(0).total_memory/1e9)"

# CPU and RAM
python -c "import os,psutil; print('cores', os.cpu_count(), 'RAM GB', round(psutil.virtual_memory().total/1e9,1))"
```

```powershell
# USB topology -- which ports share a controller (see below, this matters)
Get-PnpDevice -Class Camera,USB | Where-Object Status -eq OK |
  ForEach-Object { $_.FriendlyName; (Get-PnpDeviceProperty -InstanceId $_.InstanceId `
    -KeyName DEVPKEY_Device_LocationInfo).Data }

# Sustained write speed of the drive you plan to record to
winsat disk -drive E          # substitute your drive letter
```

### What each result should change

**GPU and VRAM.** Decides model size and whether TensorRT is worth it.
TensorRT FP16 export typically buys 2–3× over raw PyTorch and is one line
(`model.export(format='engine', half=True)`), but the first export takes
minutes and needs a working CUDA toolchain. If `torch.cuda.is_available()` is
False, stop and fix that before anything else — everything downstream assumes
it. Compute capability ≥ 7.0 means FP16 tensor cores are worth using; on a 4070
(8.9) they definitely are.

**CPU cores.** Matters more than people expect here, because **MJPEG decode
happens on the CPU and holds the GIL**. `AGENT_HANDOFF.md` §5.1 lays out the
thread structure. If you are core-starved, move JPEG decode to the GPU with
`torchvision.io.decode_jpeg(..., device='cuda')` — 1–2 ms instead of 6–12 ms,
and the frame lands where inference wants it anyway.

**USB topology — this one has already bitten this project.** Two UVC cameras
on the same hub or USB-C splitter will not both stream. Each reserves
isochronous bandwidth at start-up, so the second one is refused outright, and
Windows reports `ERROR_DEVICE_NOT_CONNECTED` (`0x8007048F`) — which is a lie,
because the device is present and works perfectly alone. **Lowering the
resolution does not rescue it:** measured on this project, the second camera
refused to start at 1080p, at 640×480 *and* at 320×240.

Compare the `LocationInfo` strings. Two cameras sharing a path prefix share an
upstream link. Put each camera on a **separate native port**, not two sockets
on the same hub. `turret_vision/dual_capture_test.py` checks this in about a
minute and tells you what does coexist.

**Disk — record to the host, copy afterwards.** That is the plan and it is the
right one. Two MJPEG streams (1080p30 + 720p30) is roughly 10–20 MB/s
sustained, and plenty of USB flash drives cannot hold that: they benchmark well
in bursts and collapse on sustained writes, at which point you drop frames
silently and only find out when the footage is unusable and everyone has gone
home. Writing to the host's internal SSD sidesteps that entirely, and the copy
to external storage afterwards is not time-critical.

Two things still worth checking: that the host has **free space** (roughly
1 GB per minute for both streams together, so budget tens of GB for a session),
and that the capture actually sustains frame rate. **Do one 60-second test
recording and count the frames before the real session** — expect 1800 per
stream at 30 fps. If you are short, you are dropping them, and no amount of
labelling fixes footage that was never captured.

**Laptop or desktop.** If it is a laptop, check whether it throttles. A model
that hits frame rate for thirty seconds and then drops as the package heats up
will look like a software bug. Run the detector flat out for five minutes and
watch `nvidia-smi` clocks before believing any benchmark.
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

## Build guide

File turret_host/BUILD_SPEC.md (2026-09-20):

# turret_host build spec

Python 3.12, Windows, RTX 5060 (Blackwell sm_120). Venv at `.venv/` already has
`opencv-python 5.0`, `torch 2.11+cu128`, `ultralytics`, `pyserial`, `numpy`, `pillow`.

**Read `turret_host/config.py` and `turret_host/types.py` first. They are the contract.**
Import constants from `config`; import dataclasses and `Slot` from `types`. Do not
redefine either. If you need a new shared type, it goes in `types.py`.

Every module must import cleanly with no hardware attached — guard hardware access
behind constructors/`start()`, never at import time. Tests run on a machine with no
camera and no board.

## Goal

A 5 mW green laser stays on a drone **held in a person's hand**, 2–5 m away, in a busy
room. It must never point at a face. Hand speeds: ≤1 m/s, ≤3 m/s².

## Architecture

```
capture-narrow ─┐
capture-wide  ──┼─> inference ─> tracker ─> control ─> link ─> Pico `vel <A> <B>`
                │                   │          │
                └───────────────────┴──────────┴──> SystemStatus ─> GUI
```

Hand-offs are `Slot`, never queues — a queue delivers stale frames the filter treats as
current.

## Modules

| file | owns |
|---|---|
| `cameras.py` | camera identification, capture threads, exposure lock |
| `detector.py` | YOLO target detection + YuNet face detection |
| `tracker.py` | pixel Kalman, adaptive Q, occlusion stabiliser, state machine |
| `control.py` | image Jacobian, control law, safety interlock |
| `link.py` | serial writer thread to the Pico |
| `calibrate.py` | Jacobian and goal-pixel calibration routines |
| `homing.py` | **auto-home at startup** — gyro cal, pitch datum, yaw datum, lash preload |
| `gui.py` | Tkinter spectator display + control panel |
| `app.py` | thread wiring, lifecycle, shutdown |

## Auto-homing (`homing.py`) — runs automatically at every startup

The system must come up on a **repeatable datum**, not "wherever it was left". Sequence,
with progress reported to the GUI (it takes tens of seconds and must not look hung):

1. **Confirm the link** and that the platform is idle. Abort loudly if not.
2. **`imu cal`** — gyro zero-rate bias, payload must be still. Uncalibrated, the X axis
   fabricates ~6 °/s, which looks exactly like mechanical drift.
3. **`level`** — drives to true level off gravity and sets the pitch datum. Repeatable
   across power cycles because gravity does not move. **Pitch only.**
4. **Yaw datum from the motor field** (below). Gravity cannot see yaw, so this is the only
   absolute yaw reference the machine has.
5. **Lash preload** — approach the final datum from one consistent direction, overshooting
   by more than `BACKLASH_DEG` and coming back. There is no `preload` firmware command
   (the doc lists one; it was never built), so do it with `dmove`/`yaw`. Always approach
   the datum the same way, every time.
6. **`sethome`** and report the established datum.

### Yaw datum from the motors' magnetic field

The magnetometer cannot give a compass heading — it is inches from two steppers whose
field swamps the earth's. But that is the signal, not the problem: **the motors' permanent-
magnet field is fixed in the base frame and rotates in the IMU frame as the payload yaws.**

Measured previously: a coarse monotonic trend of about **−4.96 LSB/deg on `my`**, plus a
resolver-like ripple of ~4 LSB at a **3.07°** period — against 3.12° predicted from the
rotor (7.2° of motor shaft ÷ 2.3077 belt ratio), a 1.7 % match.

Use `imu mag`, which replies `MAG <mx> <my> <mz> <pitch> <yaw>` — field and pose in one
round trip, so the platform cannot move between the two readings.

- Sweep yaw slowly across a modest range (±10–15° is enough), sampling at rest at each step.
  Settle before sampling; do not sample while moving.
- Fit the coarse trend and take the datum from it. Sweep in **one direction only** for the
  fit, or backlash contaminates it — the same effect that makes the `level` sensitivity
  measurement read 1.17 instead of 1.0 on a 2° probe.
- Field magnitude is ~2000 LSB against a ±2048 full scale, so **check for saturation** and
  reduce gain rather than fitting clipped data.
- The ripple period is an independent measurement of where the mechanism really is.
  Comparing its phase against the commanded position is a **direct lost-step detector** —
  expose that as a health check the GUI can show. It caps at 75 Hz so it is useless as
  tracking feedback; it is a datum and a health signal, not a servo input.
- This is the *coarse* datum. If the fit is poor, say so and fall back to using the current
  pose as yaw zero — but report clearly that yaw is unhomed.

## Hard-won constraints — violating these reproduces bugs that already cost days

**Cameras**
- **Use `cv2.CAP_MSMF`.** `CAP_DSHOW` silently delivers 10 fps at 720p while reporting 30.
- **Force MJPEG** (`CAP_PROP_FOURCC` = `MJPG`). Uncompressed YUYV modes exist at the same
  resolutions and are 3–6× slower. MSMF *refuses* the FOURCC set and returns False — that
  is normal, it negotiates the compressed mode itself. Do not "fix" it by using DSHOW.
- **MSMF silently ignores exposure writes** (`set()` returns True, value never changes).
  DSHOW honours them. To lock exposure: open briefly on DSHOW, set exposure, release,
  reopen on MSMF. UVC controls persist on the device across handles. **Verify it took.**
- **Open cameras sequentially, never concurrently.** MSMF's source reader does not
  tolerate being raced; a concurrent second open never becomes ready.
- **Grab-loop pattern is mandatory**: `cap.grab(); t = perf_counter(); cap.retrieve()` in a
  tight thread, publishing to a Slot. `CAP_PROP_BUFFERSIZE` is not settable on Windows, so
  this is the only way to defeat the driver's hidden 2–5 frame buffer.
- **Always `release()`**, including on exception and Ctrl-C. A leaked handle costs the next
  run: `isOpened()` returns True and every `read()` fails.
- **Verify delivered fps at startup** over `FPS_PROBE_FRAMES` and refuse below
  `MIN_ACCEPTABLE_FPS`. Never trust `CAP_PROP_FPS`.
- Identify the **narrow camera by serial** (`C8258920`). The max-width fingerprint cannot
  distinguish it from the built-in HP webcam, which also caps at 1280. The **wide** camera
  has no serial — use VID:PID plus the 1920 fingerprint.
- Worst-case frame gap is ~50 ms against a 33 ms median. One late frame is not a lost track.

**Detector**
- The C270's **IR-cut filter is removed**. COCO weights were trained on IR-cut imagery, so
  expect degraded confidence. **Nothing may gate on colour.** Shape and motion still work.
- Faces come from **YuNet**, not a person detector — a person detector fires on the hand
  holding the drone and the laser would never fire.
- Run the target detector on the **full 1280×720 narrow frame** at `imgsz=1280`.
- **THE FACE DETECTOR IS THE ONE PLACE THAT MUST ROTATE THE FRAME.** YuNet is a
  single-shot **upright** face detector: its anchors and its training set are upright
  faces. The narrow C270 is mounted 90° over (`NARROW_ROTATION_DEG`), so on the raw
  buffer a real face in the room is a sideways face and YuNet's recall against it
  collapses — *measured: 0 of 1 faces found on the raw buffer, 1 of 1 (conf 0.88) on the
  same frame rotated upright.* A blind face detector returns an empty list, which
  `control.py` cannot distinguish from a room with no faces in it, so the interlock would
  be **structurally blind** and the demo's whole safety story would do nothing.
  Therefore: rotate the frame fed to YuNet so faces are upright, and **map the returned
  boxes back into raw-frame coordinates** so `nearest_face_px` and the GUI overlay are
  unchanged. Rotate a **downscaled** copy (`max_side`) — a face at the 60–80 cm demo
  range is ~320 px across a raw narrow frame, so half resolution still leaves ~160 px
  against YuNet's ~15 px floor, and the downscale more than pays for the rotation
  (measured 33 ms → 7.6 ms). This does **not** apply to the drone detector: YOLO is
  trained with rotation augmentation and a drone has no canonical up, so there the
  geometry-carries-the-rotation rule stands.

**Control**
- **Feedforward is the whole game.** With ~60 ms latency the proportional term is only
  stable to ~2 Hz and cannot chase a hand. The velocity term commands the turret at the
  target's angular rate continuously.
- **The control law, with its signs, which this spec previously left undefined:**
  `omega = -J_inv @ (K*e + predicted_pixel_velocity)`, where `e = target_px - goal_px`
  and `J = d(image position of a world-fixed point)/d(motor step)` — which is how
  `calibrate.py` measures it (point at a **static** scene, step a motor, see where the
  feature went). The camera rides the payload, so a static feature moves *opposite* to the
  aim direction and that inversion is already inside the measured `J`; hence the leading
  minus. **Omitting it makes both terms positive feedback** — the P term drives the target
  away from the goal, the feedforward doubles the crossing rate — and the loop saturates
  and slews into a travel limit on the first frame it acquires. The minus belongs in the
  law, not in the stored matrix: `calibrate_jacobian()` re-derives `J` from measurement
  every run and would overwrite a hand-negated file.
- Send `vel` **every frame**, right after the detection lands. The Pico holds the rate
  between frames — that is what keeps the beam moving smoothly at 30 fps.
- `vel` takes **signed motor rates**, not payload angles. Use `vel`, not `pvel`: the
  Jacobian already maps pixel error to motor rates, and going through payload angles just
  adds a conversion that can carry a sign error.
- **Never poll `state` while servoing.** Two requests contend for one serial link; feedback
  latency roughly doubles and the watchdog parks the motors in the gap. One request, one
  answer.
- Firmware watchdog is **400 ms**. Command period must stay well under it.
- If the turret runs away from the target, a **column of `J` has the wrong sign**. Fix it
  in `J`, never in the wiring.
- Send `vel 0 0` on any transition out of TRACK.

**Safety — not tuning knobs**
- Laser on **only** when: TRACK confirmed, no face within the inhibit margin, platform
  settled, `|e| < MAX_ERROR_TO_FIRE_PX`, a `vel` went out in the last 100 ms, **and the
  goal pixel is calibrated** (see below). Any one failing → laser off **before anything
  else happens**.
- **The goal pixel must be CALIBRATED before the laser may fire.** Face clearance is
  measured from the goal pixel, i.e. from where the beam is believed to land. With no
  `goal_pixel.json` the goal falls back to frame centre, which is where the *camera*
  points; the laser's boresight offset from it has never been measured. At
  `NARROW_F_PX = 1400` one degree of offset is 24 px against a 120 px margin, and the
  sign is unknown, so it can **eat** the margin — the interlock would report 130 px of
  clearance with the beam 30 px from a face. `MAX_ERROR_TO_FIRE_PX` does not bound this:
  it certifies the target is near the goal pixel, not that the goal pixel is near the
  beam. Frame centre stays a legitimate fallback for **aiming**; it is never a fallback
  that may emit light.
- **"No data" is never "all clear."** A stale face report, a stalled frame pipeline, a
  dead camera thread and a dead serial writer are all interlock **failures**, not neutral
  states: laser off, leave the servo path, and say so on the panel. The interlock's own
  `vel_fresh` and duty-cap checks live *inside* `evaluate()`, so a loop that stops calling
  `evaluate()` has stopped enforcing them — the control loop must therefore evaluate
  liveness on **every** pass, including the passes where no new estimate arrived, not only
  when fresh data lands.
- `LASER_ENABLED` defaults False and the GUI arm control must be explicit and reversible.
- The laser goes **off immediately** on entering COAST — do not wait for the decay.

## GUI (`gui.py`)

Tkinter + PIL (both available; no new dependencies). Runs in the main thread, reads the
published `SystemStatus` and display frames from Slots. Must never touch an inference
buffer — draw on a `DISPLAY_SIZE` copy.

- Narrow view: bbox, predicted point, goal pixel, laser dot if seen.
- Wide view: all detections and every face box.
- **Large state banner**: `SEARCH` / `ACQUIRE` / `TRACK` / `INHIBITED — face` / `FIRING`.
  The inhibit banner is the demo moment; make it unmissable.
- Adaptive-Q level as a bar, so a jink is visible.
- Telemetry: per-camera fps, loop Hz, inference ms, serial RTT, pitch/yaw, pixel error.
- Controls: Start/Stop tracking, **Arm/Disarm laser** (disarmed on launch, and on every
  stop), **E-STOP** (sends `vel 0 0`, disarms, disables), and calibration triggers.
- Rotate the narrow view for display only — `NARROW_ROTATION_DEG`. For the **drone**
  detector, never rotate frames for processing; carry the rotation in the geometry instead.
  A full-frame copy per frame buys nothing. **But see the face-detector exception below —
  this rule was originally written without one, and that was a spec bug.**
- The GUI must stay responsive while tracking, and closing it must shut down cleanly:
  stop threads, `vel 0 0`, release cameras.

## Laser arming — amended 2026-09-16 after the integration review

These are behaviours the code now enforces. They are stricter than what this spec
originally described, deliberately. See `STATUS.md` for the evidence behind each.

- **A safety action latches the beam off until a human re-arms.** `link.safety_veto(latch=True)`
  — used by E-STOP, operator STOP, disarm, a dead worker thread, and shutdown — makes
  `set_laser(True)` refuse outright, independent of the safety epoch. Only `on_arm()` clears
  it. The epoch alone was not enough: a frame that read the counter *after* the safety action
  saw a consistent world and was allowed through, measured at 60/60 trials leaving the board
  with the beam on. A generation counter cannot fix that class; a latch can, because there is
  no value a racing frame can read that makes `laser on` acceptable again.
- **The control loop reads the safety epoch as the FIRST thing in a pass**, ahead of the
  tracking gate and ahead of `estimate_for_control()` (which takes the tracker lock and is
  therefore a preemption point). Anything that reads an input before reading the epoch
  reopens the race above.
- **`on_arm()` refuses until the face interlock has been proven against a real face.**
  `verify_face_interlock()` must pass in the current process. Skipped only for a simulated
  link, where nothing can emit light. This is the enforcement of pre-arm checklist item 1.
- **A refused `laser on` is abandoned, not retried.** The firmware answers a refusal by
  safe-stating every axis, so an unlatched retry loop is 55 safe_state() calls a second with
  the vel stream re-enabling the motors in between. Three attempts, then sticky refusal until
  ARM. An `off` is never abandoned.
- **The laser transact is bounded at 80 ms and sits in front of the `vel` stream**, so one
  writer pass is at most 80 + 250 = 330 ms against the firmware's 400 ms velocity watchdog.
  A 1.0 s laser timeout there made the command period exceed the watchdog outright.

### Face-detector exception — amended

- The narrow face pass **rotates its input** (`NARROW_ROTATION_DEG`) because YuNet is an
  upright-face detector and the C270 is mounted a quarter turn over. Fed the raw buffer it is
  structurally blind, and a blind face detector returns `[]`, which `control.py` cannot
  distinguish from an empty room.
- It runs at **native resolution**. A 640 downscale was tried and reverted: measured, it
  halved the range at which a face is detected at all (2.80 m → 1.40 m), which is a bystander
  standing behind the drone holder going unseen. Native costs 19.4 ms against a 33 ms frame
  period on a dedicated thread — affordable.
- **`config.py` lines 98–99 still say "never rotate frames on the processing path".** That is
  false for the face path and `config.py` is a fixed contract file, so this paragraph is the
  carve-out. Do not "fix" the code to match that comment.

## Style

Match the existing firmware's voice: comments explain *why*, especially where a choice
looks wrong but is deliberate. No defensive try/except that swallows errors. Prefer
explicit failure at startup over silent degradation at runtime.

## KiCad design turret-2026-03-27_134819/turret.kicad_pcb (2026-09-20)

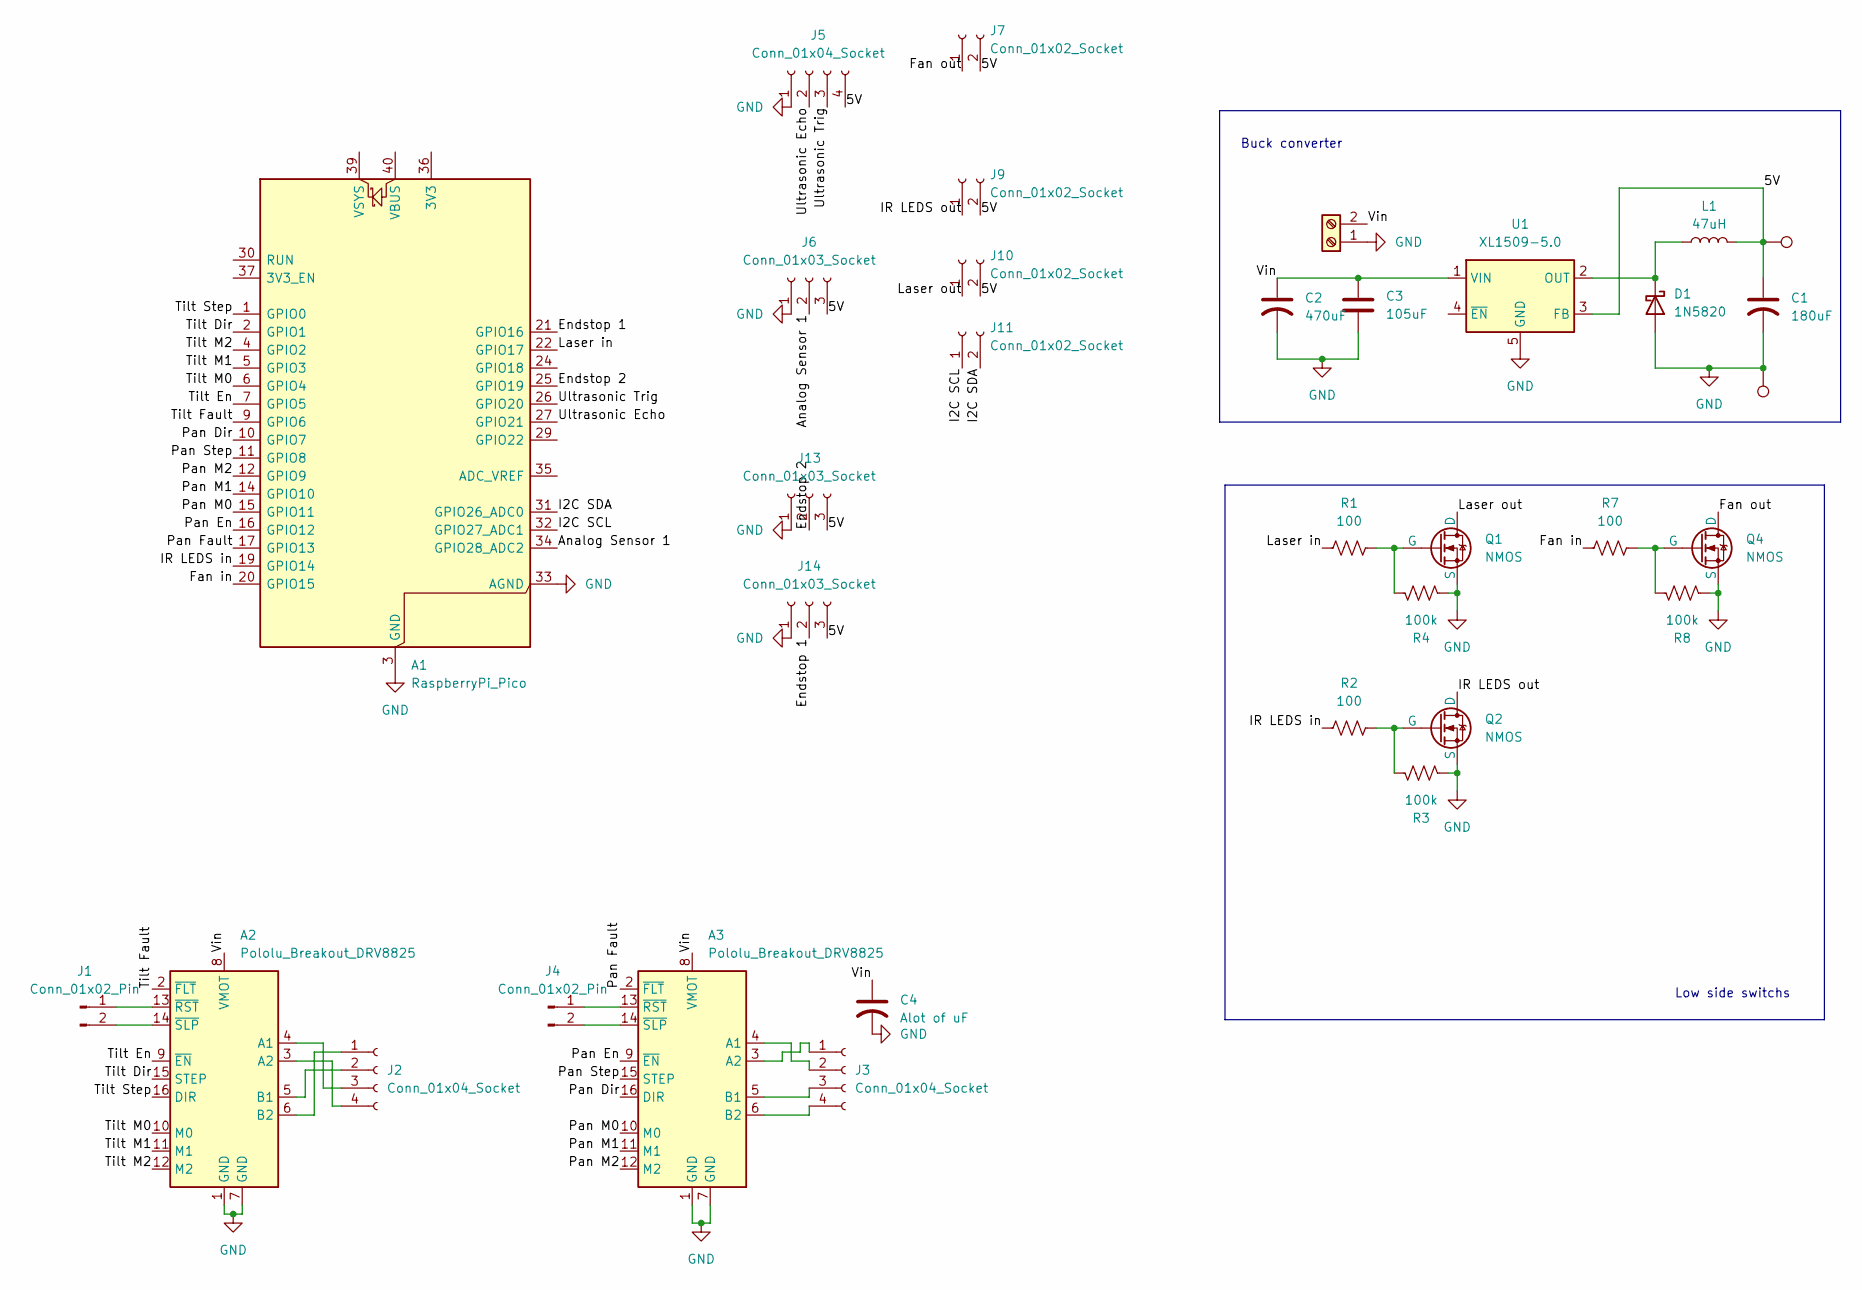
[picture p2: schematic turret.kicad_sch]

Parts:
A1: RaspberryPi_Pico; RaspberryPi_Pico_Common_Unspecified
A2, A3: Pololu_Breakout_DRV8825; Pololu_Breakout-16_15.2x20.3mm
C1: 180uF; C_Radial_D8.0mm_H11.5mm_P3.50mm
C2: 470uF; C_Radial_D8.0mm_H11.5mm_P3.50mm
C3: 105uF; C_Radial_D8.0mm_H11.5mm_P3.50mm
C4: Alot of uF; C_Radial_D16.0mm_H25.0mm_P7.50mm
D1: 1N5820; D_DO-201AD_P15.24mm_Horizontal
J1, J4: Conn_01x02_Pin; PinSocket_1x02_P2.54mm_Vertical
J2, J3, J5: Conn_01x04_Socket; JST_XH_B4B-XH-A_1x04_P2.50mm_Vertical
J6, J13, J14: Conn_01x03_Socket; JST_XH_B3B-XH-A_1x03_P2.50mm_Vertical
J7, J9, J10, J11: Conn_01x02_Socket; JST_XH_B2B-XH-A_1x02_P2.50mm_Vertical
J12: Screw_Terminal_01x02; TerminalBlock_Phoenix_MKDS-3-2-5.08_1x02_P5.08mm_Horizontal
L1: 47uH; L_10.4x10.4_H4.8
Q1, Q2, Q4: NMOS; TO-220-3_Vertical
R1, R2, R7: 100; R_Axial_DIN0207_L6.3mm_D2.5mm_P10.16mm_Horizontal
R3, R4, R8: 100k; R_Axial_DIN0207_L6.3mm_D2.5mm_P10.16mm_Horizontal
TP14, TP17: TestPoint; TestPoint_Pad_D3.0mm
U1: XL1509-5.0; SOIC-8_3.9x4.9mm_P1.27mm

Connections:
/5V: C1.1, J5.4, J6.3, J7.2, J9.2, J10.2, J13.3, J14.3, L1.2, TP14.1, U1.3 (FB)
/Analog Sensor 1: A1.34 (GPIO28_ADC2), J6.2
/Endstop 1: A1.21 (GPIO16), J14.2
/Endstop 2: A1.25 (GPIO19), J13.2
/Fan in: A1.20 (GPIO15), R7.1
/Fan out: J7.1, Q4.1 (D)
/I2C SCL: A1.32 (GPIO27_ADC1), J11.1
/I2C SDA: A1.31 (GPIO26_ADC0), J11.2
/IR LEDS in: A1.19 (GPIO14), R2.1
/IR LEDS out: J9.1, Q2.1 (D)
/Laser in: A1.22 (GPIO17), R1.1
/Laser out: J10.1, Q1.1 (D)
/Pan Dir: A1.10 (GPIO7), A3.16 (DIR)
/Pan En: A1.16 (GPIO12), A3.9 (~EN)
/Pan Fault: A1.17 (GPIO13), A3.2 (~FLT)
/Pan M0: A1.15 (GPIO11), A3.10 (M0)
/Pan M1: A1.14 (GPIO10), A3.11 (M1)
/Pan M2: A1.12 (GPIO9), A3.12 (M2)
/Pan Step: A1.11 (GPIO8), A3.15 (STEP)
/Tilt Dir: A1.2 (GPIO1), A2.15 (STEP)
/Tilt En: A1.7 (GPIO5), A2.9 (~EN)
/Tilt Fault: A1.9 (GPIO6), A2.2 (~FLT)
/Tilt M0: A1.6 (GPIO4), A2.10 (M0)
/Tilt M1: A1.5 (GPIO3), A2.11 (M1)
/Tilt M2: A1.4 (GPIO2), A2.12 (M2)
/Tilt Step: A1.1 (GPIO0), A2.16 (DIR)
/Ultrasonic Echo: A1.27 (GPIO21), J5.2
/Ultrasonic Trig: A1.26 (GPIO20), J5.3
/Vin: A2.8 (VMOT), A3.8 (VMOT), C2.1, C3.1, C4.1, J12.2, U1.1 (VIN)
GND: A1.3 (GND), A1.8 (GND), A1.13 (GND), A1.18 (GND), A1.23 (GND), A1.28 (GND), A1.33 (AGND), A1.38 (GND), A2.1 (GND), A2.7 (GND), A3.1 (GND), A3.7 (GND), C1.2, C2.2, C3.2, C4.2, D1.2 (A), J5.1, J6.1, J12.1, J13.1, J14.1, Q1.3 (S), Q2.3 (S), Q4.3 (S), R3.1, R4.2, R8.1, TP17.1, U1.5 (GND), U1.6 (GND), U1.7 (GND), U1.8 (GND)
unnamed: A2.4 (A1), J2.3
unnamed: A2.3 (A2), J2.4
unnamed: A2.5 (B1), J2.2
unnamed: A2.6 (B2), J2.1
unnamed: A2.13 (~RST), J1.1
unnamed: A2.14 (~SLP), J1.2
unnamed: A3.4 (A1), J3.2
unnamed: A3.3 (A2), J3.1
unnamed: A3.5 (B1), J3.3
unnamed: A3.6 (B2), J3.4
unnamed: A3.13 (~RST), J4.1
unnamed: A3.14 (~SLP), J4.2
unnamed: D1.1 (K), L1.1, U1.2 (OUT)
unnamed: Q1.2 (G), R1.2, R4.1
unnamed: Q2.2 (G), R2.2, R3.2
unnamed: Q4.2 (G), R7.2, R8.2

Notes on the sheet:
Low side switchs
Buck converter

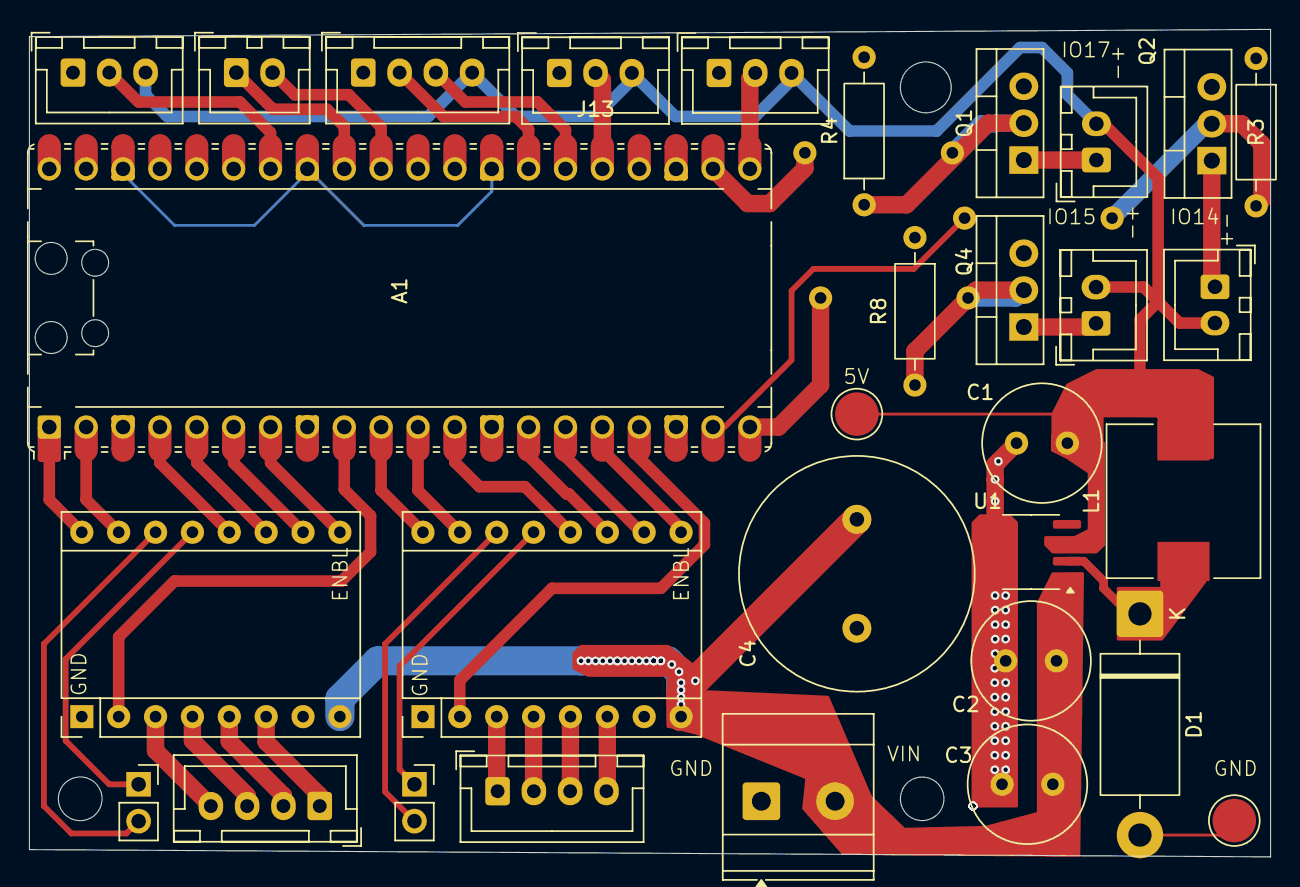
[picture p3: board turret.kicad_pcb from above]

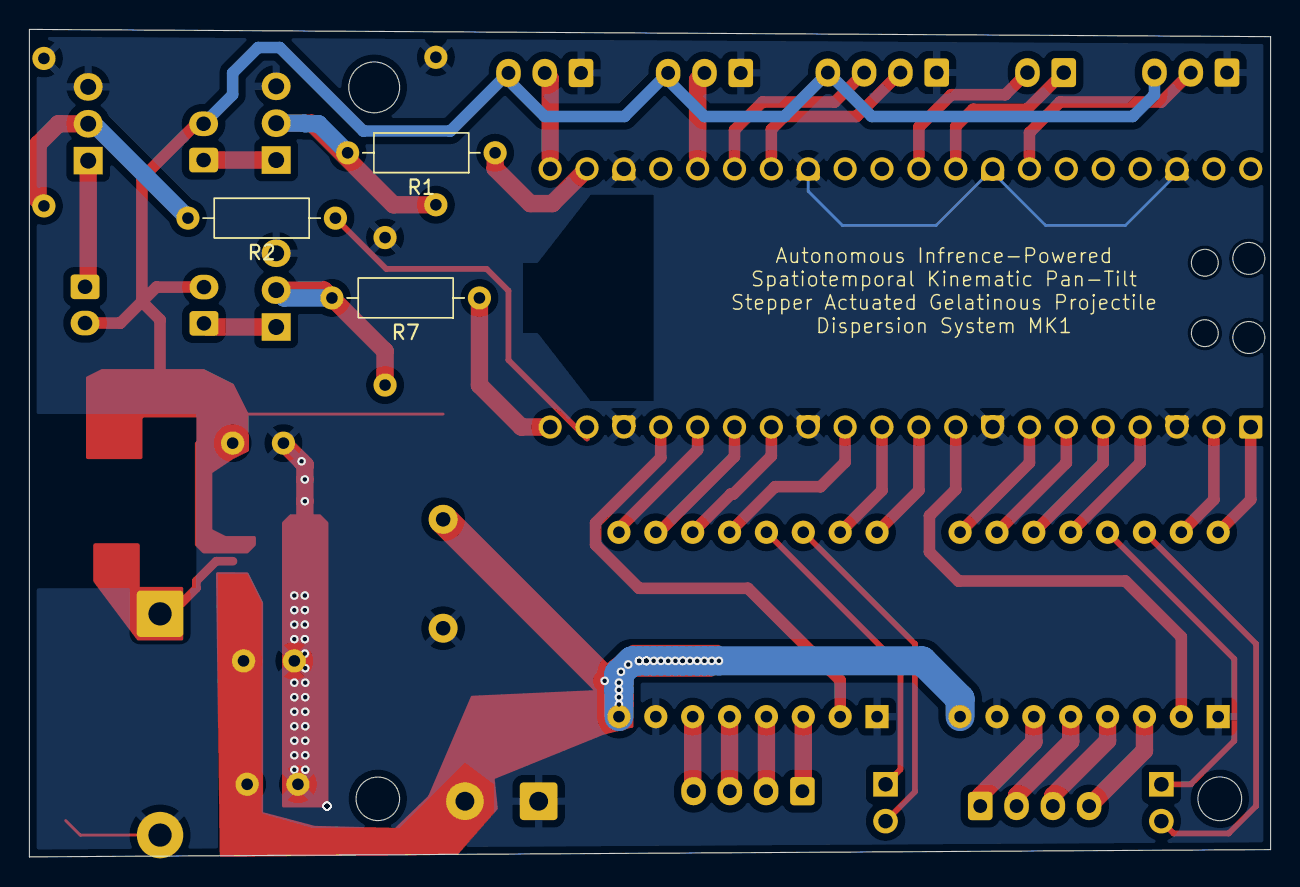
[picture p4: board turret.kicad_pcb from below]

Board: 2 copper layers, 85.5 x 57.0 mm, 34 parts (3 on the bottom side), 46 nets.

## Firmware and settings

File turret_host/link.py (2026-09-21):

"""Serial link to the Pico: a dedicated writer thread and a 1-deep slot.

WHY A THREAD AT ALL
-------------------
The control loop must never block on USB. A Windows USB CDC write can stall for
tens of milliseconds when the host controller is busy, and the control thread is
also the thread that decides whether the laser may be on. So the control thread
only ever does `slot.put(...)` -- a lock, an assignment, an event set -- and a
separate serial thread drains the slot and does the blocking I/O. Newest-wins:
if the serial thread is behind, the stale rate is overwritten and never sent.
Sending a rate that is two frames old is worse than not sending it.

THE ONE RULE THAT COST DAYS
---------------------------
**Never poll `state` while servoing.** Two outstanding requests contend for one
serial link, each blocking the other; the feedback latency roughly doubles and
the firmware's 400 ms watchdog parks the motors in the gap. The symptom is a
turret that steps between poses instead of tracking, and it looks exactly like
a tuning problem. One request, one answer. Every blocking helper in this module
therefore refuses to run while the servo path is active -- see `_require_idle`.

WHY THERE IS NO KEEPALIVE
-------------------------
This module deliberately does NOT re-send the last rate when the control loop
goes quiet. The firmware watchdog parking the motors after 400 ms of silence is
the safety behaviour we want; a link-level keepalive would defeat it and leave a
motor holding its last rate forever after the control thread died.

WHY `vel` AND NOT `pvel`
------------------------
`vel` takes signed MOTOR rates. The image Jacobian already maps pixel error
straight to motor rates, so routing through payload angles only adds a
conversion that can carry a sign error.
"""
# Running this file as a script (`python turret_host/link.py`) puts
# turret_host/ at the FRONT of sys.path instead of the project root. That
# breaks the absolute imports below -- and worse, `turret_host/types.py` then
# SHADOWS THE STDLIB `types` MODULE, so the very next `import threading` dies
# inside enum/functools with a baffling circular-import error. So drop the
# script directory and put the project root in its place, which is exactly the
# path layout `python -m turret_host.link` produces.
#
# Guarded on __package__: an ordinary `import turret_host.link` never runs this
# and never touches sys.path.
if __package__ in (None, ""):                                    # noqa: E402
    import os as _os
    import sys as _sys
    _here = _os.path.dirname(_os.path.abspath(__file__))
    _sys.path = [p for p in _sys.path
                 if _os.path.abspath(p or _os.getcwd()) != _here]
    _sys.path.insert(0, _os.path.dirname(_here))

import math
import re
import threading
import time

import serial
import serial.tools.list_ports

from turret_host import config
from turret_host.types import ControlOutput, LinkStatus, Slot


PROMPT = b"turret>"

# Host-side I/O policy. These are this module's own timing, not platform
# constants -- nothing here duplicates config.py.
#
# `timeout` is the hard ceiling on one reply. `settle` is the quiet gap that
# ends a reply when the prompt has not arrived yet: the console prints progress
# lines with long silent gaps while the platform is physically moving, and a
# short settle would cut the reply off mid-move and leave the rest of the
# output to be misread as the *next* command's reply.
_BLOCKING_TIMEOUTS = {
    # (timeout_s, settle_s)
    "imu cal": (25.0, 2.0),      # averages gyro samples for ~10 s
    # 2026-09-20: motion commands print nothing while the platform moves, and a
    # move longer than the settle window returned "no reply" three times today
    # (dmove 48 deg at 6 deg/s = 8 s of silence against a 5 s settle; the
    # step-check rewind's 1.07 s move against the 1.0 s default). For anything
    # that moves, the quiet gap is the full timeout: wait for the prompt.
    "level": (240.0, 240.0),
    "aim": (60.0, 60.0),
    "dmove": (60.0, 60.0),
    "move": (60.0, 60.0),
    "yaw": (60.0, 60.0),
    "sethome": (10.0, 1.0),
    "home": (60.0, 60.0),
    "imu mag": (6.0, 0.5),
    "state": (6.0, 0.5),
    "stop": (6.0, 0.5),
}
_DEFAULT_BLOCKING_TIMEOUT = (10.0, 1.0)

# The vel round trip is "ok\r\nturret> " and nothing else. If it has not come
# back inside this, the link is in trouble and we want to know now, not after
# the watchdog has already parked the motors.
_VEL_TIMEOUT_S = 0.25
_VEL_SETTLE_S = 0.05
#: DIR resync before the first real rate of a link's life -- see
#: TurretLink._resync_vel_dir. 20 steps/s for ~12 ms is a quarter of a
#: microstep: no visible motion, but the firmware's velocity tick writes the
#: DIR pin on each sign it sees.
_DIR_RESYNC_RATE = 20.0
_DIR_RESYNC_DWELL_S = 0.012

# The laser transact sits IN FRONT OF the vel stream on the writer thread (an
# "off" must never queue behind a rate update), so its timeout is part of the
# command period the firmware's 400 ms velocity watchdog is counting.
#
# It used to be timeout=1.0, settle=0.1 -- 2.5x the watchdog, in front of the
# stream, retried on every pass with no backoff. Measured against a board that
# answered `vel` but not `laser`: vel fell to 1.7 Hz with a worst gap of
# 1033 ms, tripping the watchdog; a single healthy 120 ms laser round trip
# already blew the 150 ms VEL_COMMAND_PERIOD_MAX_MS budget.
#
# The budget now: _LASER_TIMEOUT_S + _VEL_TIMEOUT_S = 80 + 250 = 330 ms worst
# case for one pass, which is under the 400 ms watchdog. A laser transition the
# board does not answer inside 80 ms is not going to be saved by waiting a
# second for it -- what it needs is for the vel stream to keep running while we
# retry, and for the operator to be told.
_LASER_TIMEOUT_S = 0.08
_LASER_SETTLE_S = 0.01

# Minimum spacing between retries of a laser transition the board rejected.
# Without it a refusal is retried at writer-loop rate: measured at 165 commands
# and 165 errors in 3 s (55 Hz). On the real firmware a refused `laser on force`
# makes cli.py call safe_state() -- aborting and disabling every axis -- so that
# storm is 55 safe_state() calls a second with the vel stream re-enabling the
# motors in between, not a harmless log flood.
_LASER_RETRY_S = 0.25

# How many times a REFUSED "on" is retried before it is abandoned and latched
# off. An "on" the board will not accept is not a safety problem -- the beam is
# dark, which is the direction we want -- so it is given up on. An "off" is
# never abandoned: it is retried for as long as the writer lives.
_LASER_ON_ATTEMPTS = 3

# After `vel 0 0` the firmware RAMPS to zero rather than dropping the rate, so
# leaving velocity mode immediately would abandon a still-moving motor and fold
# a stale count back into the position counter. Worst case is MAX_MOTOR_RATE
# (4000 steps/s) over the firmware's VEL_ACCEL of 40000 steps/s^2 = 100 ms; 150
# gives margin without making shutdown feel hung.
_VEL_RAMP_DOWN_S = 0.15

# Serial read timeout on the persistent handle. Kept small so `read(1)` wakes
# within a fraction of the frame period instead of busy-polling `in_waiting`.
_READ_TIMEOUT_S = 0.02

_RTT_EMA_ALPHA = 0.2             # published rtt_ms is smoothed; GUI readability

# How long close() will wait for the io lock before giving up on parking the
# motors and just releasing the handle. close() runs on the Tk MAIN THREAD, so
# this is a bound on how long the window takes to shut -- it is deliberately
# far below the 240 s `level` timeout a platform task can be holding, and above
# a normal `vel` round trip (~10 ms) plus the ramp.
_CLOSE_IO_TIMEOUT_S = 2.0

# How long close() waits for the io lock for the BEAM-OFF alone, before the
# longer wait for the motor park. Short on purpose: it runs on the Tk main
# thread, and if a platform command is holding the port for its full 240 s we
# want to get to the unlocked last-resort write, not sit here.
_CLOSE_LASER_LOCK_S = 0.3


class LinkError(RuntimeError):
    """The board is not where we left it, or did not answer."""


class LinkBusy(LinkError):
    """A blocking command was attempted while the servo path is live.

    This is the `state`-while-servoing bug made impossible rather than
    documented. Stop the servo first.
    """


# ==========================================================================
#   Port discovery and REPL recovery  (patterns from tools/send.py)
# ==========================================================================
def find_port():
    """The Pico's COM port, resolved by VID/PID. COM numbers move; VID/PID
    does not."""
    for p in serial.tools.list_ports.comports():
        if p.vid == config.PICO_VID and p.pid == config.PICO_PID:
            return p.device
    return None


def _read_reply(ser, timeout, settle):
    """Read until the prompt returns, or until the board goes quiet.

    Returns (text, saw_prompt). The echoed command line is still in `text`;
    the caller strips it because only the caller knows what it sent.
    """
    buf = bytearray()
    deadline = time.monotonic() + timeout
    last = time.monotonic()
    saw_prompt = False
    while time.monotonic() < deadline:
        n = ser.in_waiting
        # read(1) blocks up to the port timeout and returns the instant a byte
        # lands, so this costs no CPU and adds well under a millisecond to the
        # measured RTT. A sleep-poll loop would quantise every round trip to
        # the sleep interval.
        chunk = ser.read(n if n else 1)
        if chunk:
            buf += chunk
            last = time.monotonic()
            if buf.rstrip().endswith(PROMPT):
                saw_prompt = True
                break
        elif buf and time.monotonic() - last > settle:
            break
    text = buf.decode("utf-8", "replace")
    lines = [ln for ln in text.splitlines() if ln.strip() != PROMPT.decode()]
    return "\n".join(lines).strip(), saw_prompt


def _at_repl(port):
    """True if the board sits at the bare MicroPython REPL, not the console."""
    with serial.Serial(port, config.SERIAL_BAUD, timeout=0.3) as ser:
        time.sleep(0.25)
        ser.reset_input_buffer()
        ser.write(b"\r\n")
        time.sleep(0.4)
        banner = ser.read(ser.in_waiting or 1).decode("utf-8", "replace")
    if PROMPT.decode() in banner:
        return False
    return ">>>" in banner


def _reset_into_console(port, report=None):
    """Reboot the board so main.py runs and starts the console.

    main.py is __main__-guarded, so importing it is not enough -- only a real
    reset starts the CLI. machine.reset() re-enumerates the USB CDC device, so
    the handle dies and the COM port disappears and comes back under a
    possibly different name; that is why we re-resolve by VID/PID in the wait
    loop instead of reopening the name we had. Safe: main.py parks every pin
    before the CLI starts.
    """
    if report:
        report("board at REPL -- resetting into the console")
    try:
        with serial.Serial(port, config.SERIAL_BAUD, timeout=0.3) as ser:
            ser.write(b"import machine; machine.reset()\r\n")
            ser.flush()
            time.sleep(0.2)
    except serial.SerialException:
        # The reset tears the CDC device down mid-write. This specific failure
        # is the expected outcome of the command succeeding, not an error to
        # report -- the loop below is what decides whether it worked.
        pass

    deadline = time.monotonic() + 15.0
    while time.monotonic() < deadline:
        time.sleep(0.4)
        p = find_port()
        if not p:
            continue
        try:
            with serial.Serial(p, config.SERIAL_BAUD, timeout=0.3) as ser:
                time.sleep(0.3)
                ser.reset_input_buffer()
                ser.write(b"\r\n")
                time.sleep(0.5)
                if PROMPT in ser.read(ser.in_waiting or 1):
                    return p
        except serial.SerialException:
            continue                       # still re-enumerating; keep waiting
    raise LinkError("board did not return a turret> prompt after reset")


# ==========================================================================
#   MAG parsing
# ==========================================================================
def parse_mag(reply):
    """Parse the `imu mag` reply: "MAG <mx> <my> <mz> <pitch> <yaw>".

    Returns (mx, my, mz, pitch_deg, yaw_deg) -- field as ints in LSB, pose in
    degrees. Field and pose come from ONE round trip on purpose: sampling them
    with two commands lets the platform move between the two readings and
    silently corrupts the yaw-datum fit.

    Saturation is not checked here. Full scale and what to do about a clipped
    axis are homing's business; this function reports what the board said.
    """
    for line in reply.splitlines():
        line = line.strip()
        if not line.startswith("MAG "):
            continue
        parts = line.split()
        if len(parts) != 6:
            raise LinkError("malformed MAG reply (want 5 fields): %r" % line)
        return (int(parts[1]), int(parts[2]), int(parts[3]),
                float(parts[4]), float(parts[5]))
    raise LinkError("no MAG line in reply: %r" % reply)


def _parse_pose(reply):
    """Pull "pitch <p>  yaw <y>" out of a human-formatted reply, if present.

    The move/home replies all carry the resulting pose. Scraping it costs
    nothing and keeps LinkStatus fresh without a second round trip -- which is
    the whole point of this module.
    """
    pose = None
    for line in reply.splitlines():
        parts = line.replace(",", " ").split()
        for i in range(len(parts) - 3):
            if parts[i] == "pitch" and parts[i + 2] == "yaw":
                try:
                    pose = (float(parts[i + 1]), float(parts[i + 3]))
                except ValueError:
                    continue               # "pitch <deg> yaw" in help text
    return pose                            # last one wins: it is the newest


# ==========================================================================
#   TurretLink
# ==========================================================================
class TurretLink:
    """The serial link. Construct freely; `start()` touches the hardware.

    Threading contract:
      * control thread  -> submit()/send_vel()/stop()   (never blocks on I/O)
      * serial thread   -> owns the port while servoing
      * setup code      -> the blocking helpers, only when NOT servoing
    """

    def __init__(self, port=None, on_message=None):
        # Nothing here opens a port: this module must import and construct on
        # a machine with no board attached.
        self._forced_port = port
        self._on_message = on_message      # optional progress sink for the GUI
        self.last_gear_report = None       # last ACK, includes its own timestamp

        self._ser = None
        self._port = ""
        # Exactly one transaction at a time. RLock, not Lock, so close() can
        # take it with a TIMEOUT and still run the park sequence through
        # _transact() on the same thread -- see close(). Cross-thread mutual
        # exclusion is unchanged.
        self._io_lock = threading.RLock()

        self.vel_slot = Slot()             # control -> serial, newest wins
        self.status_slot = Slot()          # link -> GUI

        self._writer = None
        self._stop_event = threading.Event()

        self._stat_lock = threading.Lock()
        self._connected = False
        self._sent = 0
        self._errors = 0
        self._last_error = ""
        self._rtt_ms = 0.0                 # EMA, for a readable GUI number
        self._rtt_ms_last = 0.0            # the most recent measurement
        self._pitch = 0.0
        self._yaw = 0.0
        self._last_vel_ok_t = None         # perf_counter of the last good vel
        self._vel_seq_sent = 0             # slot seq the writer has completed
        self._vel_progress = threading.Event()
        # The rates the board last ACKNOWLEDGED, not the ones we queued, and
        # the safety epoch they were queued under. stop() confirms on both,
        # because a sequence number can be satisfied by an item that overwrote
        # the zeros, and zeros acknowledged before this stop() say nothing
        # about a non-zero rate that is being written right now -- see stop().
        self._last_rates_sent = None
        self._last_rate_epoch = -1
        # Bumped by every safety action (stop/E-STOP/disarm/close). A caller
        # that decided "laser on" or "rate X" against an older epoch has
        # decided against a world that no longer exists, so its command is
        # dropped rather than applied. This is what stops an in-flight vel from
        # overwriting E-STOP's zeros, and an in-flight FIRING from outliving a
        # disarm by one frame.
        self._safety_epoch = 0
        # Hard beam latch, set by safety_veto(latch=True) -- E-STOP, operator
        # STOP, disarm, a dead worker thread, shutdown. While it is set,
        # set_laser(True) is REFUSED outright, regardless of epoch, and only an
        # explicit clear_beam_latch() from the operator's ARM path clears it.
        #
        # This is deliberately not the epoch mechanism. The epoch is a
        # generation counter, and every counter-based scheme has the same
        # shape of hole: a caller that reads the counter after the safety
        # action sees a consistent-looking world and is allowed through. Moving
        # the read to the top of the control pass closes today's instance of
        # that hole; this latch closes the CLASS, because it is not a
        # comparison -- there is no value a racing frame can read that makes
        # `laser on` acceptable again. An E-STOP must be undone by a human.
        #
        # stop() deliberately does NOT latch: it runs on every TRACK->SEARCH
        # transition, and latching there would mean the beam never returns when
        # a target is reacquired, which is an inhibit-everything failure
        # dressed up as safety.
        self._beam_latched = False
        # Set once the writer thread has exited for good (port lost, or stopped
        # and joined). A laser request with nothing to carry it is an error,
        # not a success -- see set_laser().
        self._writer_gone = False
        # One report per link for the undeliverable-laser-request condition:
        # the control loop asks 30 times a second.
        self._laser_path_reported = False

        # True between the first send_vel() and the next stop(). Blocking
        # helpers refuse while it is set.
        self._servo_active = False
        # Two separate facts, because the firmware's `stop` settles one and
        # not the other:
        #   _motors_live      we enabled the coils by sending `vel`, so they
        #                     must be zeroed before we let go of the port.
        #   _vel_mode_entered the 200 Hz velocity loop is running, so it must
        #                     be left (which folds the dead-reckoning
        #                     accumulator back into the step counter).
        # `vel` auto-enables the motors, so neither may be assumed: sending
        # `vel 0 0` at shutdown when we never servoed would energise the coils
        # on the way out the door.
        self._motors_live = False
        self._vel_mode_entered = False

        # Laser state, driven from the writer thread -- see set_laser().
        # _want is what the interlock asked for; _is is what the board was
        # actually told. They differ only for the few ms it takes the writer
        # to notice. Both start False: nothing here ever arms by default.
        self._laser_want = False
        self._laser_is = False
        # Retry accounting for a laser transition the board rejects. See
        # _service_laser(): rejections are spaced by _LASER_RETRY_S so they
        # cannot starve the vel stream, and a rejected "on" is abandoned after
        # _LASER_ON_ATTEMPTS instead of being hammered forever.
        self._laser_next_try = 0.0
        self._laser_on_tries = 0
        # Set when an "on" was abandoned, so the control loop can tell the
        # operator the beam is NOT lit despite the interlock permitting it.
        self._laser_on_failed = False
        # Wakes the writer immediately on a new rate or a laser transition,
        # instead of waiting out the slot's poll timeout.
        self._wake = threading.Event()

    # ------------------------------------------------------------------
    #   lifecycle
    # ------------------------------------------------------------------
    def start(self):
        """Resolve the board, recover it from the REPL if needed, open the
        port and start the writer thread. Raises rather than degrading."""
        if self._ser is not None:
            raise LinkError("already started")

        port = self._forced_port or find_port()
        if not port:
            raise LinkError(
                "no MicroPython board %04x:%04x found -- check USB, and that "
                "nothing else holds the port (only one process may)"
                % (config.PICO_VID, config.PICO_PID))

        if _at_repl(port):
            port = _reset_into_console(port, report=self._report)

        ser = serial.Serial(port, config.SERIAL_BAUD, timeout=_READ_TIMEOUT_S)
        self._ser = ser
        self._port = port
        # Let the CDC endpoint settle, then throw away whatever banner or
        # half-line was sitting in the buffer. Anything left here would be
        # read as the first command's reply.
        time.sleep(0.25)
        ser.reset_input_buffer()

        reply = self._transact("", timeout=3.0, settle=0.4)
        if reply is None:
            raise LinkError("board on %s did not answer with a turret> prompt"
                            % port)
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

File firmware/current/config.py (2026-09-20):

"""
User-editable configuration for the turret test suite.

Everything you are likely to want to change lives here.  pinmap.py is
hardware truth and should not need editing.
"""

# ==========================================================================
#   WHICH DRIVER CHIP IS ACTUALLY SOLDERED/SOCKETED IN?
# ==========================================================================
# "A4988"   -- Allegro A4988 carrier.  Pad 2 is VDD (logic supply input).
# "DRV8825" -- TI DRV8825 carrier.     Pad 2 is nFAULT (open-drain output).
#
# This changes the microstep truth table AND how pad 2 is treated.  Getting
# it wrong at 1/16 microstepping gives silently wrong step counts, because
# A4988 wants M=111 and DRV8825 wants M=001 for 1/16.
DRIVER_TYPE = "A4988"

# How to treat driver pad 2 when DRIVER_TYPE == "A4988".
#   "external"  -- (RECOMMENDED) you bodged the pad-2 net to Pico 3V3.
#                  The suite leaves the GPIO as a high-Z input and never
#                  drives it.  Safe.
#   "gpio"      -- EXPERIMENTAL.  Drive the GPIO high at 12 mA drive strength
#                  and let it act as the A4988's logic supply.  Marginal but
#                  usually works (A4988 I_DD is ~5 mA typ, 10 mA max).  The
#                  driver is unpowered until firmware boots, so never leave
#                  VMOT applied across a Pico reset in this mode.
#   "off"       -- leave the pin alone entirely; drivers will not work.
A4988_VDD_SOURCE = "gpio"

# Where the RESET+SLEEP jumper wire is tied.  J1 (tilt) and J4 (pan) bring
# RST and SLP out; both chips need them high to run, so they get shorted
# together and pulled up.
#
#   "3V3"  -- (REQUIRED for A4988) tied to 3.3 V.  Works for both chips.
#   "5V"   -- tied to the 5 V rail.  Fine for a DRV8825 (5.75 V abs max on
#             digital pins), but it VIOLATES the A4988's absolute maximum:
#             A4988 logic inputs are rated -0.3 V to VDD + 0.3 V, so at
#             VDD = 3.3 V the ceiling is 3.6 V and 5 V is 1.4 V over.  See
#             HARDWARE_NOTES.md Finding #4 -- it back-drives the Pico.
#   "none" -- no jumper.  Drivers stay in reset and will not step.
#
# 2026-09-16: this is ACTUALLY WIRED TO 5 V, not 3V3.  The value said "3V3"
# and AGENT_HANDOFF Finding #4 claimed it had been reworked; neither was true,
# so `state` was reporting the wrong thing.  Corrected to match the hardware.
# The builder has run these specific drivers at 5 V repeatedly without failure
# and accepts the out-of-spec condition; this field is informational only and
# locks nothing out.
RST_SLP_TIED_TO = "5V"

# ==========================================================================
#   MOTOR / MECHANICS
# ==========================================================================
FULL_STEPS_PER_REV = 200        # 1.8 deg NEMA 17.  Use 400 for a 0.9 deg motor.

# --------------------------------------------------------------------------
#   DIFFERENTIAL WRIST
# --------------------------------------------------------------------------
# Two steppers drive the input bevel gears of a differential through timing
# belts.  The payload (cameras + laser) rides on the output gear.
#
#   both motors the SAME direction     -> carrier rotates -> PITCH (up/down)
#   both motors OPPOSITE directions    -> output spins    -> YAW   (left/right)
#   one motor alone                    -> half of each, simultaneously
#
# So neither motor is a "pitch motor" or a "yaw motor".  The firmware still
# calls the two axes "pan" and "tilt" for historical reasons -- read those as
# MOTOR A and MOTOR B.  kinematics.py converts between the two worlds.
BELT_TEETH_MOTOR = 26           # pulley on the stepper shaft
BELT_TEETH_MITER = 60           # pulley on the miter/input gear
BELT_RATIO = BELT_TEETH_MITER / BELT_TEETH_MOTOR   # 60/26 = 2.3077 : 1
MITER_RATIO = 1.0               # bevel gears are 1:1

# Combined reduction from motor shaft to miter input.
DIFFERENTIAL_N = BELT_RATIO * MITER_RATIO

# Sign of each motor relative to the ideal kinematics.  Flip if a commanded
# +pitch drives the payload down, or +yaw drives it right instead of left.
# NOTE finding #5: J2 and J3 have mirrored pin orders, so the two motors turn
# opposite ways for the same electrical direction.  These constants absorb it
# -- do NOT re-pin a connector to "fix" direction.
MOTOR_SIGN = {"pan": 1, "tilt": 1}      # pan = MOTOR A, tilt = MOTOR B

# Which way is positive, for the operator's sanity.
#   +pitch = payload nose UP        +yaw = payload turns LEFT (CCW from above)
# Flip these after the first `dchar` run if reality disagrees.
#
# pitch flipped 2026-09-15 against the hardware: a commanded +pitch drove the
# payload DOWN, the opposite of the 3D viewer and of the convention above.
# Verified by driving the real turret, not by reasoning -- which is the only
# way a sign convention can be settled.
PAYLOAD_SIGN = {"pitch": -1, "yaw": 1}
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

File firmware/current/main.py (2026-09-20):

"""
Entry point.  MicroPython runs main.py automatically at boot.

Boot order matters here: every pin is parked in its safe state BEFORE
anything else happens, so that a reset mid-move cannot leave a driver
enabled or the laser on.
"""

import sys

import config
import pinmap
from machine import Pin


def park_all_pins():
    """
    Force everything to its safe resting state.

    - driver EN high  (active low, so high = coils released)
    - STEP/DIR low
    - all three MOSFET gates low (laser, IR, fan off)
    - driver pad 2 left as a high-Z input until stepper.py claims it,
      so we never drive into an external 3V3 bodge
    """
    for axis in (pinmap.PAN, pinmap.TILT):
        Pin(axis["en"], Pin.OUT, value=1)
        Pin(axis["step"], Pin.OUT, value=0)
        Pin(axis["dir"], Pin.OUT, value=0)
        for k in ("m0", "m1", "m2"):
            Pin(axis[k], Pin.OUT, value=0)
        Pin(axis["fault"], Pin.IN, None)

    for gpio in pinmap.OUTPUTS.values():
        Pin(gpio, Pin.OUT, value=0)

    Pin(pinmap.ULTRASONIC_TRIG, Pin.OUT, value=0)


def main():
    park_all_pins()
    import cli
    cli.main()


if __name__ == "__main__":
    try:
        main()
    except KeyboardInterrupt:
        park_all_pins()
        print("\ninterrupted -- pins parked safe.  You are at the REPL.")
    except Exception as e:
        park_all_pins()
        sys.print_exception(e)
        print("\npins parked safe.  You are at the REPL.")

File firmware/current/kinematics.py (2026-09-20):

"""
Differential wrist kinematics -- the layer between motors and payload axes.

The two stepper drivers are called "pan" and "tilt" everywhere else in this
suite. On this platform those names are wrong and actively misleading: the
motors drive the input bevels of a differential, so **neither one is a payload
axis**. Read them as MOTOR A (pan / A3) and MOTOR B (tilt / A2).

    both motors, same direction        -> carrier turns    -> PITCH
    both motors, opposite directions   -> output gear spins -> YAW
    one motor alone                    -> half of each, at once

    pitch = (thetaA + thetaB) / 2N        thetaA = N * (pitch + yaw)
    yaw   = (thetaA - thetaB) / 2N        thetaB = N * (pitch - yaw)

N is the belt reduction (60T miter pulley / 26T motor pulley = 2.3077), the
miters being 1:1. Everything here is linear, so the same transform maps
velocities as well as positions.

Pure Python, no dependencies -- runs on the Pico and on the host test stubs.
"""

import config

# --------------------------------------------------------------------------
# scalar helpers
# --------------------------------------------------------------------------


def motor_step_deg(microstep):
    """Degrees of motor shaft per microstep."""
    return 360.0 / (config.FULL_STEPS_PER_REV * microstep)


def axis_step_deg(microstep):
    """
    Payload degrees when BOTH motors take one step together.

    This is the platform's resolution on a cardinal axis -- pure pitch or
    pure yaw.
    """
    return motor_step_deg(microstep) / config.DIFFERENTIAL_N


def diagonal_step_deg(microstep):
    """
    Payload degrees in EACH axis when only ONE motor steps.

    Half the cardinal resolution, in both axes simultaneously. The platform
    can therefore position more finely than `axis_step_deg` suggests, just
    not along a single axis.
    """
    return axis_step_deg(microstep) / 2.0


def steps_per_axis_rev(microstep):
    """
    Motor steps for one full payload revolution on a cardinal axis.

    Deliberately returned as a float: with a 26T pulley this is 7384.6, not an
    integer, so a whole revolution does not land back on a step boundary.
    Track position in steps and convert to degrees on read -- never the other
    way round, or the error accumulates.
    """
    return 360.0 / axis_step_deg(microstep)


# --------------------------------------------------------------------------
# the transform
# --------------------------------------------------------------------------


def motor_to_payload(steps_a, steps_b, microstep):
    """Motor step counts -> (pitch_deg, yaw_deg)."""
    sd = motor_step_deg(microstep)
    n = config.DIFFERENTIAL_N
    tha = steps_a * sd * config.MOTOR_SIGN["pan"]
    thb = steps_b * sd * config.MOTOR_SIGN["tilt"]
    pitch = (tha + thb) / (2.0 * n) * config.PAYLOAD_SIGN["pitch"]
    yaw = (tha - thb) / (2.0 * n) * config.PAYLOAD_SIGN["yaw"]
    return pitch, yaw
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

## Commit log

2026-10-27 feat(camera): support configurable replacement narrow camera profiles
2026-10-27 feat(calibration): bind image geometry to camera and mount identity
2026-10-27 feat(timing): track capture provenance and separate prediction command lead
